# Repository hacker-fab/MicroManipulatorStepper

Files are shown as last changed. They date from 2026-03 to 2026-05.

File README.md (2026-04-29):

# HackerFab Nanopositioner

This repository contains **HackerFab’s extended version** of the open-source nanopositioner originally developed by Diffraction Limited.

We build directly on the original design and contribute additional capabilities, including:
- Rotational control
- Integrated heating
- Vacuum compatibility
- Ongoing improvements for lab use at HackerFab

## Credit

All core mechanical, electrical, and firmware design work is credited to the original project:

https://github.com/0x23/OpenMicroManipulator  

This repo is a derivative work that extends their platform for new use cases with additional custom made components. 

## Documentation

For build instructions, usage, and full system details, see the HackerFab documentation:

https://docs.hackerfab.org/home

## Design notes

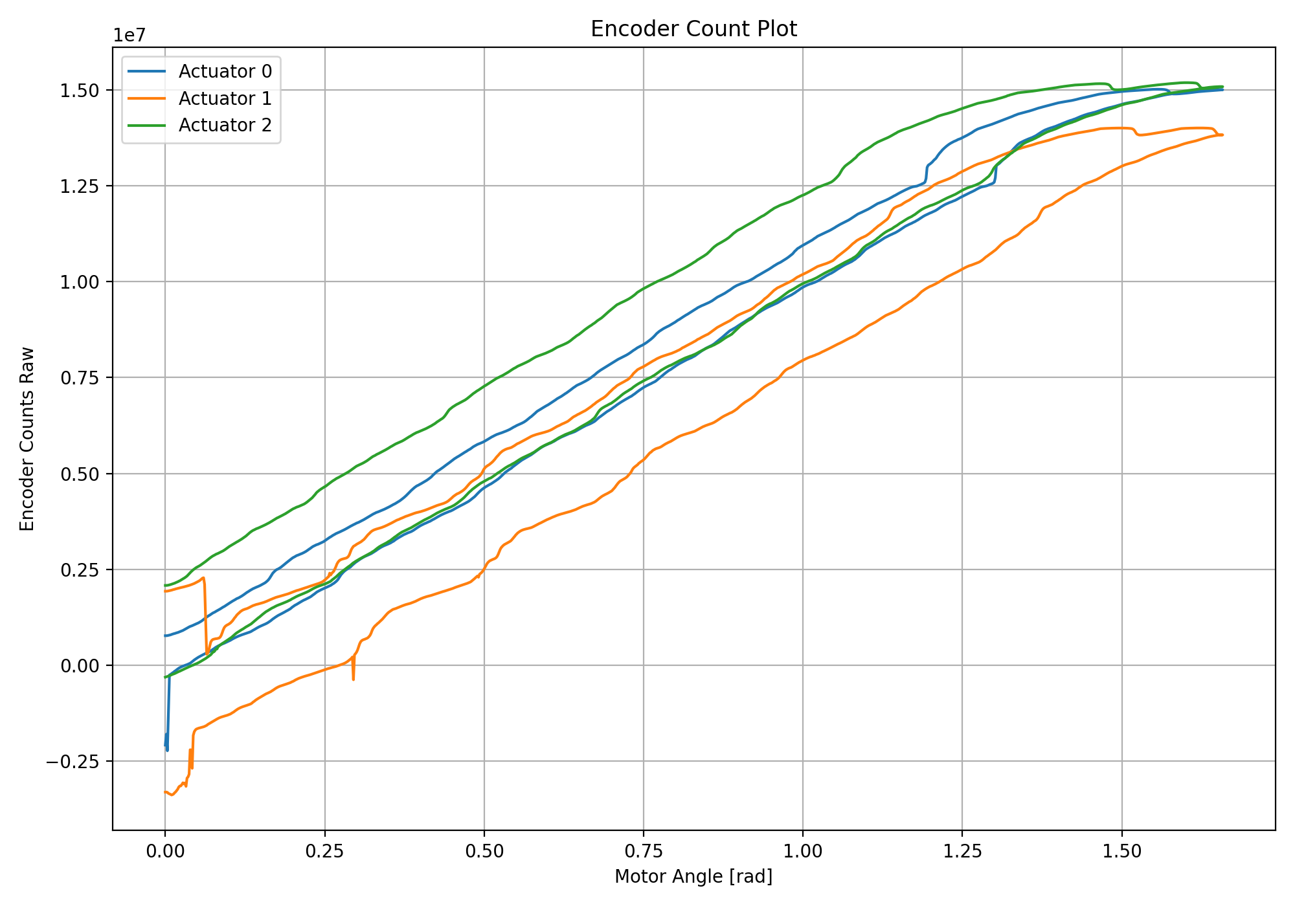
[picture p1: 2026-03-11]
software/PythonAPI/my_figure.png

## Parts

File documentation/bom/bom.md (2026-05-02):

# Bill of Materials (BOM)

## Mechanics

| Name | Qty | Description | Comments | Suggested link | Image |
|---|-----|---|---|---|---|
| Steel ball | 12 | Ø1 mm (0.04") | Precision G10 or better. Can be sourced from small ball bearings | |
| PU stretch cord | 1 m | Ø1mm | e.g. "Stretch Magic" or "Magic String" | [Aliexpress](https://www.aliexpress.us/item/3256805953910514.html)| Pu strech cord|
| Neodym Cylinder Magnet | 70 | Ø3mm h=5 mm | N52 Grade | [NeoMagnets](https://www.buyneomagnets.com/p/3mm-dia-x-5mm-thick-n52-neodymium-rare-earth-disc-magnets-100-pack/)|
| Brass Pipe | 1 m | OD=Ø2mm ID=Ø1 mm |  | [Amazon](https://a.co/d/1pRFmtf)| Brass Pipe|
| M2-8 dowel | 9 | | | | |
| SHCS M2-8 | 9 | | | | |
| Set Screw M3-6 | 3 | | | | |
| FHCS M3-6 | 3 | | | | |
| FHCS M3-10 | 9 | | | | |
| FHCS M3-20 | 12  | | | | |

## Electronics

| Name | Qty | Description | Comments | Suggested link | Image |
|---|-----|---|---|---|---|
| DC-DC Step Down Module | 1 | 4.75–23 V Step-Down Buck Converter |  | [Aliexpress](https://www.aliexpress.us/item/3256806752772875.html)| DC-DC Step Down|
| (1N5819) OR (PMEG4010) | 1 | Diode (through-hole or SMD) |  | |
| Raspberry Pi Pico 2 | 1 | Microcontroller board |  | | Raspberry Pi Pico 2|
| MT6835 Magnetic Encoder Module | 3 | Magnetic encoder |  | [Aliexpress](https://www.aliexpress.us/item/3256808005140674.html)| MT6835 Magnetic Encoder Module|
| TB6612FNG Driver | 3 | |  | [Aliexpress](https://www.aliexpress.us/item/3256806060073976.html)| TB6612FNG Driver|
| 470 µF Electrolytic Capacitor | 3 | > 100 µF | anything > 100µF will work well | |
| 10 µF Ceramic Capacitor 0603 | 3 | Optional |  | |
| 4.7 k Resistor 0603 | 2 | Optional |  | |
| 2 Pin Power Header | 1 | 7.5 mm pitch |  | |
| 4 Pin Header | 4 | 2.5 mm pitch |  | |
| 8 Pin Header | 1 | 2.0 mm pitch |  | |
| NEMA 17 Stepper Motor | 3 | Body ≤ 38 mm | Body length <= 38mm | |

## PCBs

| Name | Qty | Description | Comments | Image |
| --- | --- | --- | --- | ----- |
| Control Board | 1 | | | |
| balljoint_plate_pcb | 6 | | | |

## 3D Printing

| Name | Qty | Description | Comments | Image |
| --- | --- | --- | --- | --- |
| Motor Horn | 3 | | 0.4 mm+ nozzle may require post-processing | Motor Horn |
| RubberBandCollet | 12  | | 0.4 mm nozzle, 0.1mm Layer height + may require post-processing | Rubber Band Collet |
| Motor Mount | 3 | | | Motor Mount |
| End Effector | 1 | | | End Effector |
| Base Block | 1 | | | Base Block |

# Tool - Rod Sharpener

## 3D Printing

| Name | Qty | Description | Comments | Image |
| --- | --- | --- | --- | ----- |
| Rod Guide | 1 | | | |
| Blade Carrier | 1 | | | |

# Tool - Rod Length Setting Press

## PCBs

| Name | Qty | Description | Comments | Image |
| --- | --- | --- | --- | ----- |
| ball_alignment_disc_pcb | 1 | | | |

## 3D Printing 

| Name | Qty | Description | Comments | Image |
| --- | --- | --- | --- | ----- |
| RodGrindingJigA | 1 | | | |
| RodGrindingJigB | 1 | | | |
| RodGuide | 1 | | | |
| RodCollet | 2 | | | |
| CaliperClamp | 2 | | | |

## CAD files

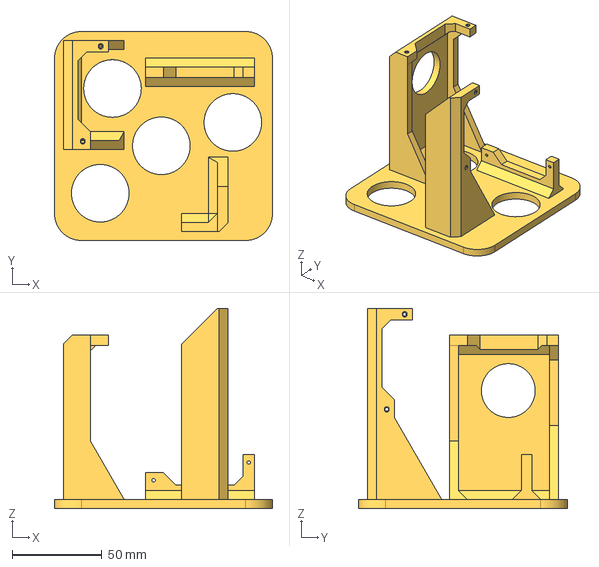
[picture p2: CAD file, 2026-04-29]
construction/Litho Base Mount.step
121.5 x 116.5 x 111.5 mm

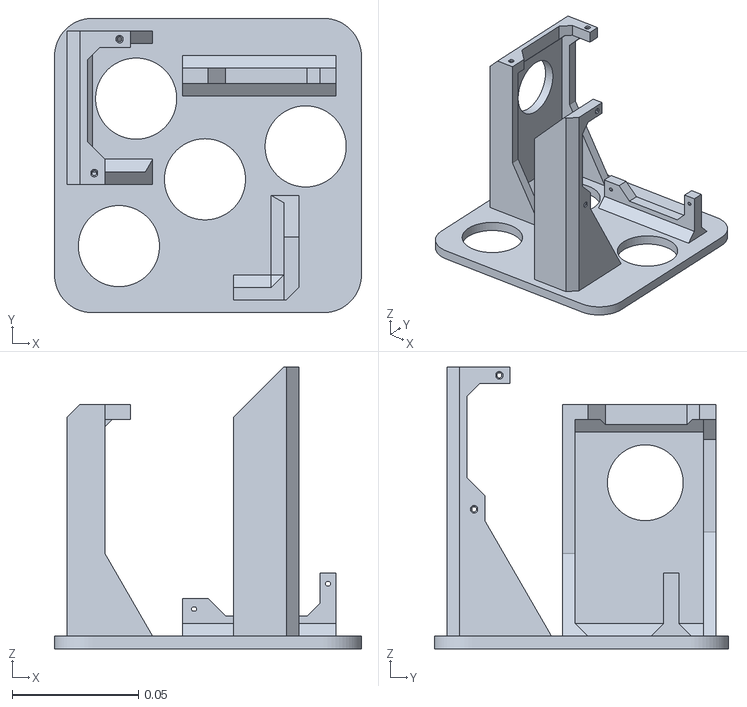
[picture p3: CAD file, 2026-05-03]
construction/v4_3dprinting_stl/machine/StandingBase.stl
0.122 x 0.116 x 0.112

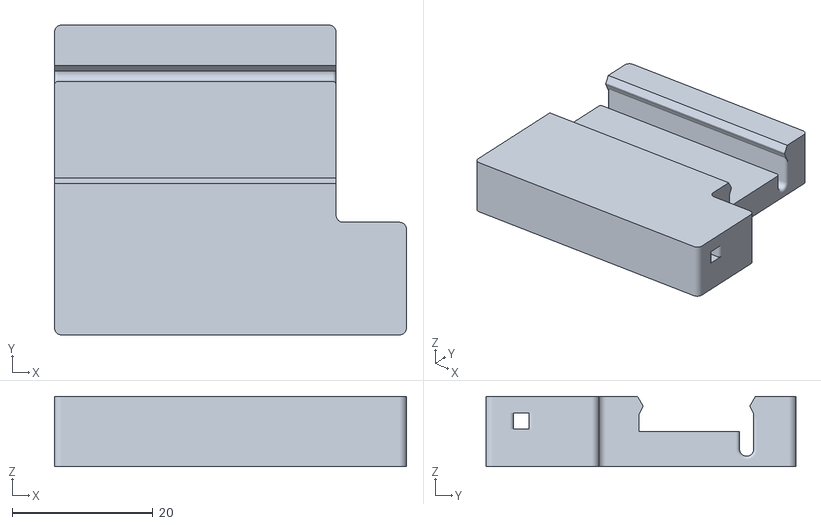
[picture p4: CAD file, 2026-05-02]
construction/v4_3dprinting_stl/tools/rod_length_setting_press/RodGuide.stl
50.0 x 44.0 x 10.0

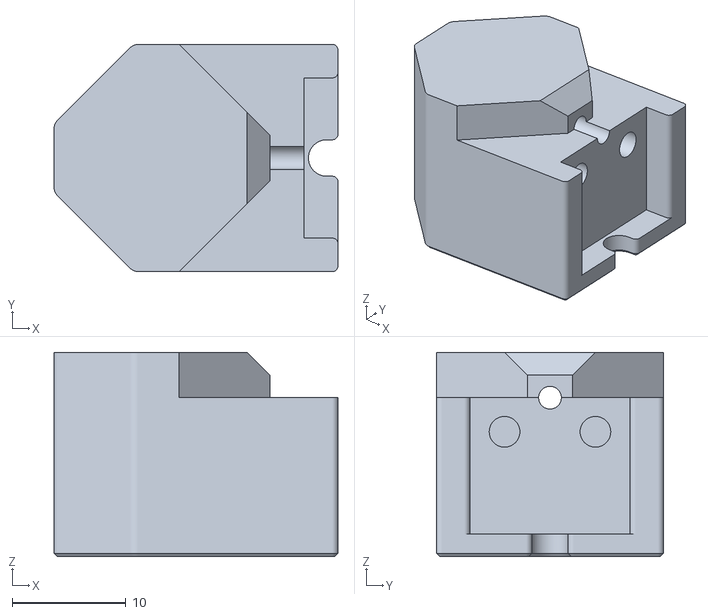
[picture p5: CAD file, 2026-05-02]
construction/v4_3dprinting_stl/tools/rod_sharpener/RodGuide.stl
25.0 x 20.0 x 18.0

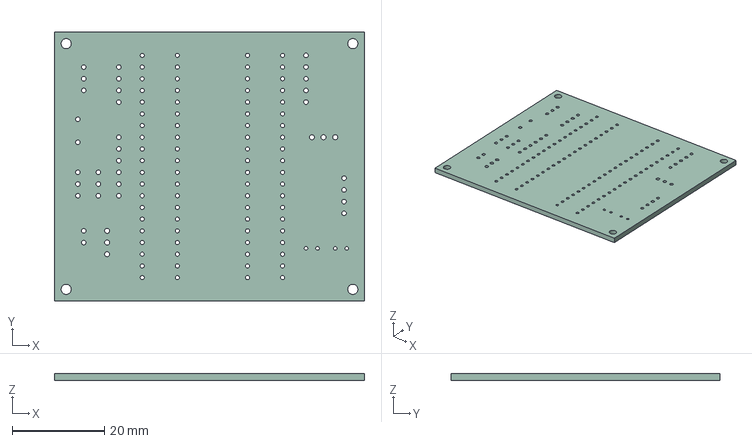
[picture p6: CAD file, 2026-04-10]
electronics/rot_platform_pcb/rot_platform_pcb.step
67.3 x 58.4 x 1.51 mm

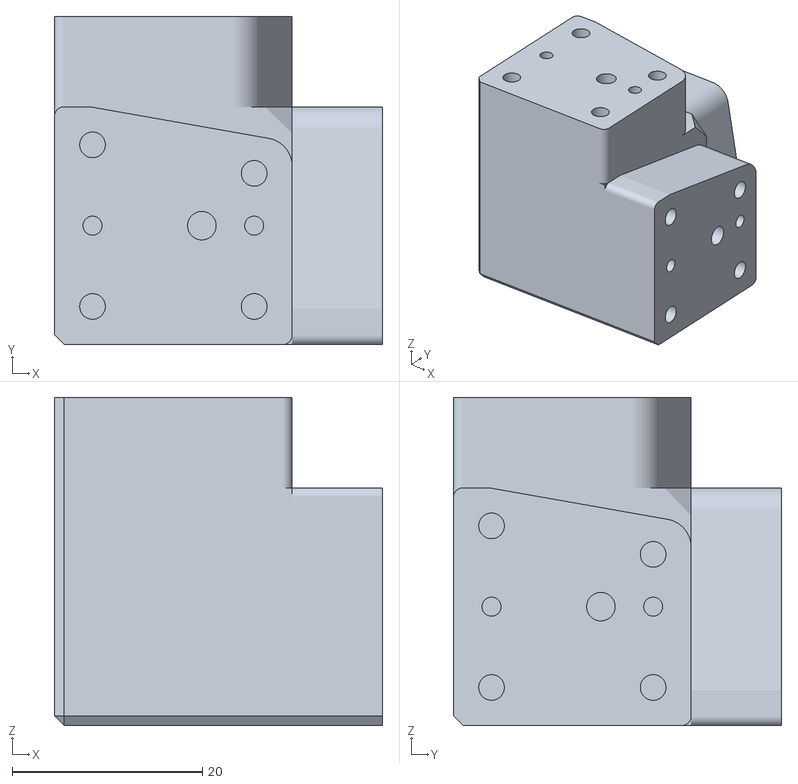
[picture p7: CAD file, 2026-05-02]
construction/v4_3dprinting_stl/machine/BaseBlock.stl
34.5 x 34.5 x 34.5

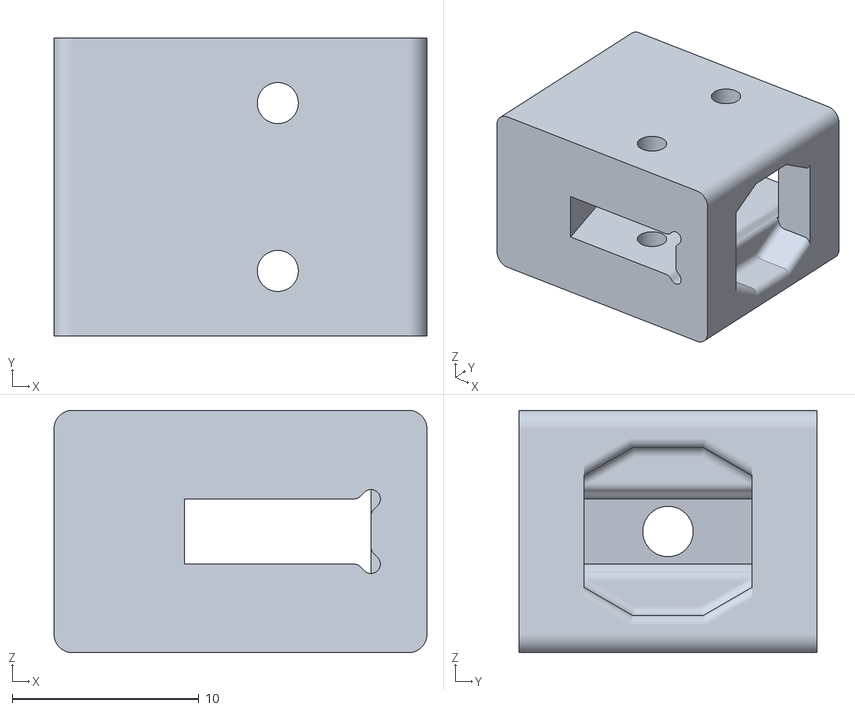
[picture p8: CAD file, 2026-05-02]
construction/v4_3dprinting_stl/tools/rod_length_setting_press/CaliperClamp.stl
20.0 x 16.0 x 13.0

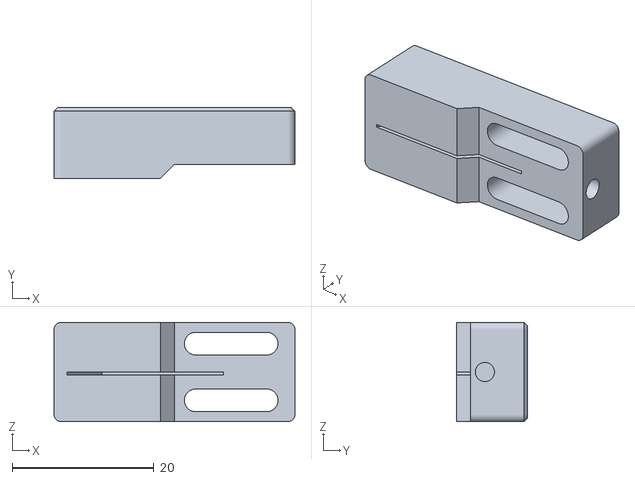
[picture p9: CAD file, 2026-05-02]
construction/v4_3dprinting_stl/tools/rod_sharpener/BladeCarrier.stl
34.0 x 10.0 x 14.0

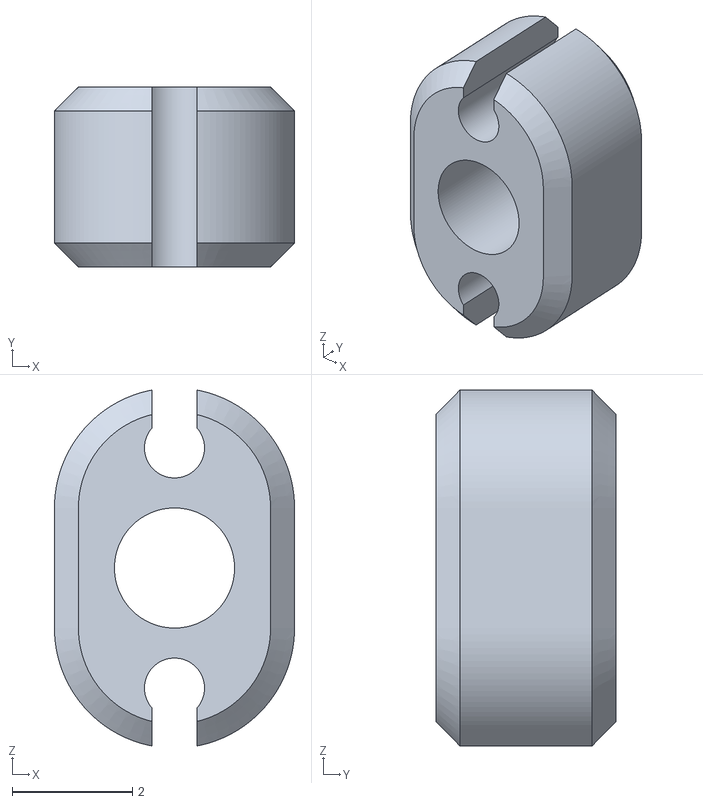
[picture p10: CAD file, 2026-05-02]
construction/v4_3dprinting_stl/machine/RubberBandCollet.stl
4.00 x 3.00 x 5.93

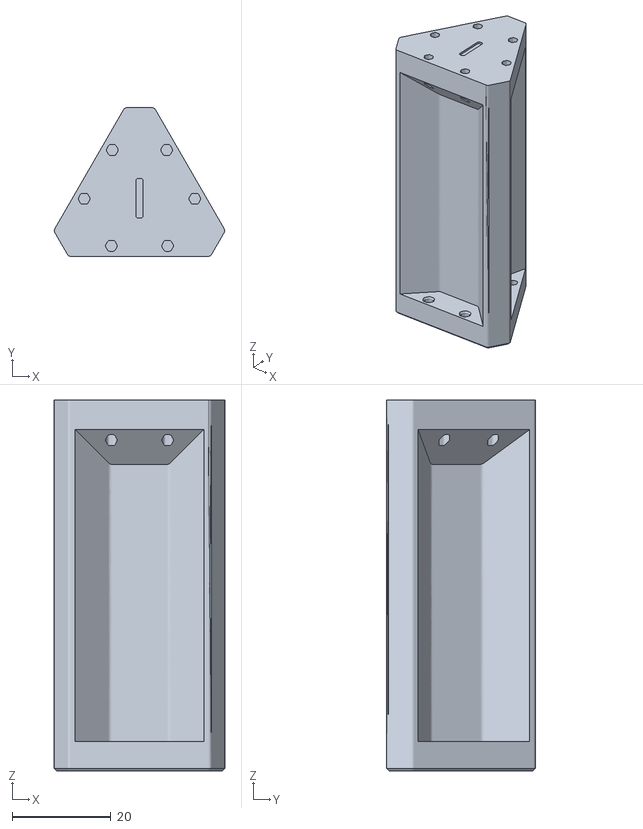
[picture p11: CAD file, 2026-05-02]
construction/v4_3dprinting_stl/tools/rod_length_setting_press/RodGrindingJigA.stl
34.5 x 30.1 x 75.0

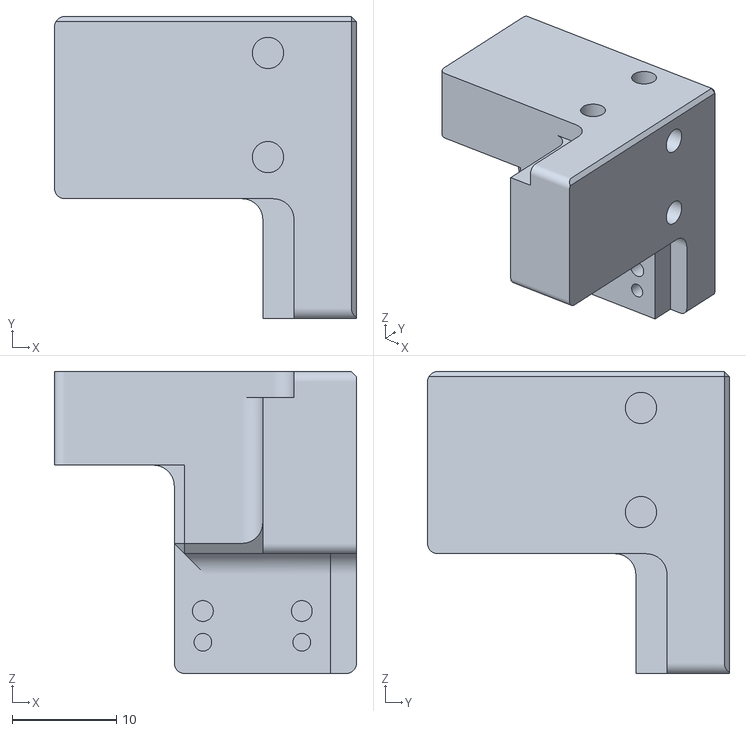
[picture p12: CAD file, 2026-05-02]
construction/v4_3dprinting_stl/machine/EndEffector.stl
29.0 x 29.0 x 29.0

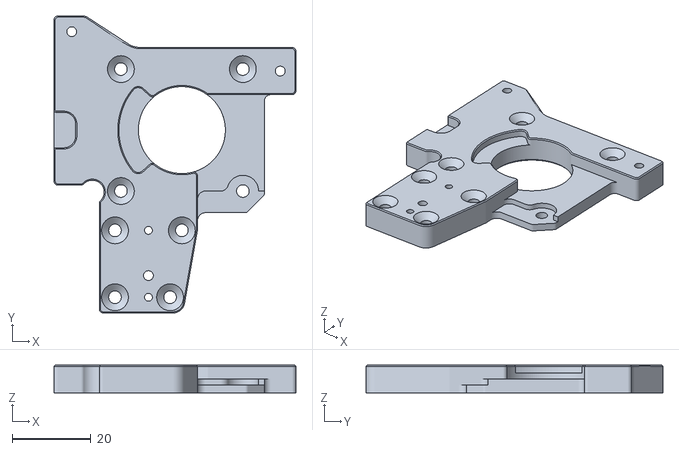
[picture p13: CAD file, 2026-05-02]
construction/v4_3dprinting_stl/machine/MotorMount.stl
61.5 x 75.5 x 7.00

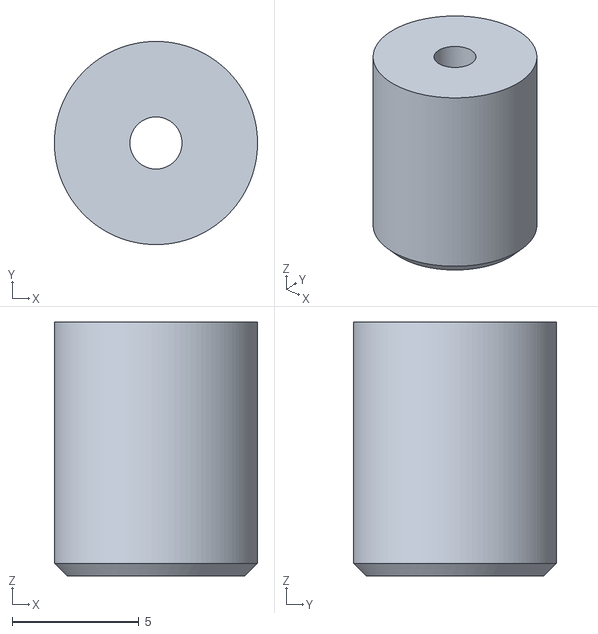
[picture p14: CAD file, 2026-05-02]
construction/v4_3dprinting_stl/tools/rod_length_setting_press/RodCollet.stl
8.00 x 8.00 x 10.0

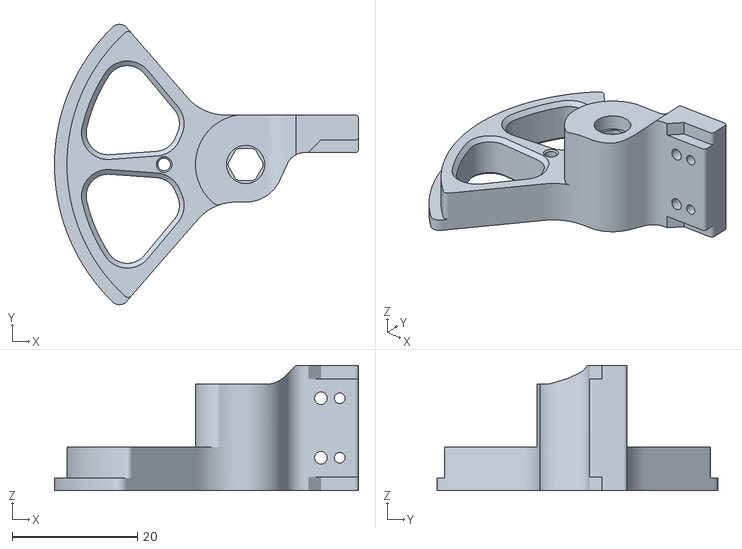
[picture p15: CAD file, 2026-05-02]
construction/v4_3dprinting_stl/machine/MotorHorn.stl
48.5 x 44.7 x 20.0

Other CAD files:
construction/v4_3dprinting_stl/tools/rod_length_setting_press/RodGrindingJigB.stl

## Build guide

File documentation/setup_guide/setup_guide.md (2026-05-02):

# Setup Guide

This guide walks you through the setup of your new **Open Micro-Manipulator** device.

## Checklist for New Devices

1. **Was the mechanical limit pin added to the rotor?**  
   This pin is required for proper homing of the device.

    <div style="display: flex;">
        Mechanical Limit Pin
    </div>

2. **Are the screws that secure the rotor to the motor shaft installed?**  
   If the rotor is not firmly attached, it may slip imperceptibly during homing or other movements, leading to problems during calibration and homing.

3. **Is the homing direction correct?**  
   During the homing command (`G28`), the end effector should move toward the base.  
   If it moves in the opposite direction, rewire the motor to reverse its direction.

   <div style="display: flex;">
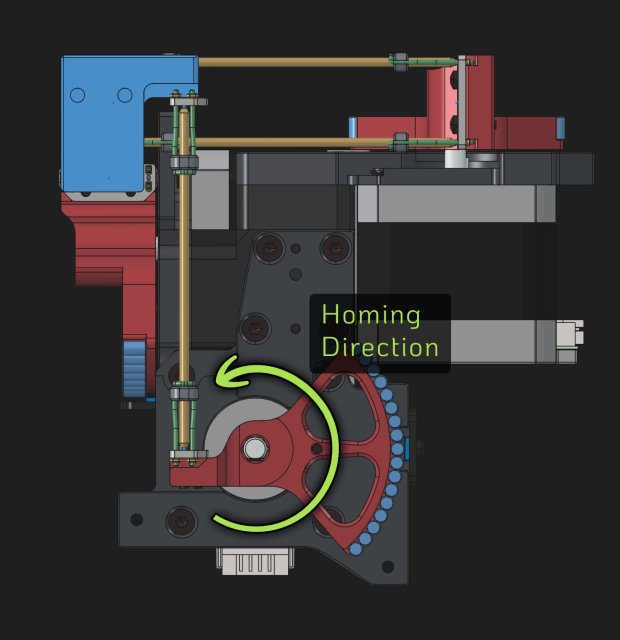
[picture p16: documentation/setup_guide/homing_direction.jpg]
Mechanical Limit Pin
       
   </div>

## Calibration and Checking the Encoders

You can use the calibration plotter to check if your encoders are working as expected.
On the left you see a good calibration on the right a bad calibration.

|  |  |
:--:|:--:
| **Good calibration** | **Bad calibration** |

THIS DOCUMENT IS UNFINISHED AND WORK IN PROGRESS...

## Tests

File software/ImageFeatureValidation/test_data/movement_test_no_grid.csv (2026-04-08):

x | y | feed | delay
0.000000 | 0.000000 | 10.0
0.001000 | 0.000000 | 50.0
0.002000 | 0.000000 | 50.0
0.001000 | 0.000000 | 50.0
0.000000 | 0.000000 | 50.0
0.000000 | 0.001000 | 50.0
0.000000 | 0.002000 | 50.0
0.000000 | 0.001000 | 50.0
0.000000 | 0.000000 | 50.0
0.000707 | 0.000707 | 50.0
0.001414 | 0.001414 | 50.0
0.000707 | 0.000707 | 50.0
0.000000 | 0.000000 | 50.0
-0.000707 | 0.000707 | 50.0
0.000000 | 0.001414 | 50.0
0.000707 | 0.000707 | 50.0
0.000000 | 0.000000 | 50.0
0.001000 | 0.000000 | 50.0
0.000293 | 0.000707 | 50.0
0.001000 | 0.001414 | 50.0
0.001707 | 0.000707 | 50.0
0.001000 | 0.000000 | 50.0
0.000000 | 0.000000 | 50.0
-0.000707 | -0.000707 | 50.0
0.000293 | -0.000707 | 50.0
0.001293 | -0.000707 | 50.0
0.000586 | 0.000000 | 50.0
0.000000 | 0.000000 | 50.0
0.001000 | 0.000000 | 50.0
0.002000 | 0.000000 | 50.0
0.001000 | 0.000000 | 50.0
0.000000 | 0.000000 | 50.0
0.000000 | 0.001000 | 50.0
0.000000 | 0.002000 | 50.0
0.000000 | 0.001000 | 50.0
0.000000 | 0.000000 | 50.0
0.000707 | 0.000707 | 50.0
0.001414 | 0.001414 | 50.0
0.000707 | 0.000707 | 50.0
0.000000 | 0.000000 | 50.0
-0.000707 | 0.000707 | 50.0
0.000000 | 0.001414 | 50.0
0.000707 | 0.000707 | 50.0
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

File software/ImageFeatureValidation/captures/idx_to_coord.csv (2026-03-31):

idx | x | y
0 | -7.0 | 0.0
1 | 0.001000000000000334 | 0.0
2 | 0.0019999999999997797 | 0.0
3 | 0.001000000000000334 | 0.0
4 | 0.0 | 0.0
5 | 0.0 | 0.001
6 | 0.0 | 0.002
7 | 0.0 | 0.001
8 | 0.0 | 0.0
9 | 0.0007070000000002352 | 0.000707
10 | 0.0014139999999995823 | 0.001414
11 | 0.0007070000000002352 | 0.000707
12 | 0.0 | 0.0
13 | -0.0007070000000002352 | 0.000707
14 | 0.0 | 0.001414
15 | 0.0007070000000002352 | 0.000707
16 | 0.0 | 0.0
17 | 0.001000000000000334 | 0.0
18 | 0.00029300000000009874 | 0.000707
19 | 0.001000000000000334 | 0.001414
20 | 0.001706999999999681 | 0.000707
21 | 0.001000000000000334 | 0.0
22 | 0.0 | 0.0
23 | -0.0007070000000002352 | -0.000707
24 | 0.00029300000000009874 | -0.000707
25 | 0.0012930000000004327 | -0.000707
26 | 0.0005860000000001975 | 0.0
27 | 0.0 | 0.0
28 | 0.001000000000000334 | 0.0
29 | 0.0019999999999997797 | 0.0
30 | 0.001000000000000334 | 0.0
31 | 0.0 | 0.0
32 | 0.0 | 0.001
33 | 0.0 | 0.002
34 | 0.0 | 0.001
35 | 0.0 | 0.0
36 | 0.0007070000000002352 | 0.000707
37 | 0.0014139999999995823 | 0.001414
38 | 0.0007070000000002352 | 0.000707
39 | 0.0 | 0.0
40 | -0.0007070000000002352 | 0.000707
41 | 0.0 | 0.001414
42 | 0.0007070000000002352 | 0.000707
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

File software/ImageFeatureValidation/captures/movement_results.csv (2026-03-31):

from_position | to_position | expected_distance_um | actual_distance_um | difference_um | feed
(-7.000000000,0.000000000) | (0.001000000,0.000000000) | 1.0 | 2.947063171070284 | 1.9470631710702841 | 50.0
(0.001000000,0.000000000) | (0.002000000,0.000000000) | 1.0 | 1.3242024965505383 | 0.32420249655053834 | 50.0
(0.002000000,0.000000000) | (0.001000000,0.000000000) | 1.0 | 0.9471770879675141 | -0.0528229120324859 | 50.0
(0.001000000,0.000000000) | (0.000000000,0.000000000) | 1.0 | 1.716676845021542 | 0.7166768450215419 | 50.0
(0.000000000,0.000000000) | (0.000000000,0.001000000) | 1.0 | 2.948005388172818 | 1.948005388172818 | 50.0
(0.000000000,0.001000000) | (0.000000000,0.002000000) | 1.0 | 2.1853585354504927 | 1.1853585354504927 | 50.0
(0.000000000,0.002000000) | (0.000000000,0.001000000) | 1.0 | 1.9705077073768327 | 0.9705077073768327 | 50.0
(0.000000000,0.001000000) | (0.000000000,0.000000000) | 1.0 | 2.121842257667226 | 1.1218422576672258 | 50.0
(0.000000000,0.000000000) | (0.000707000,0.000707000) | 0.999848988597778 | 2.44425217800624 | 1.4444031894084621 | 50.0
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

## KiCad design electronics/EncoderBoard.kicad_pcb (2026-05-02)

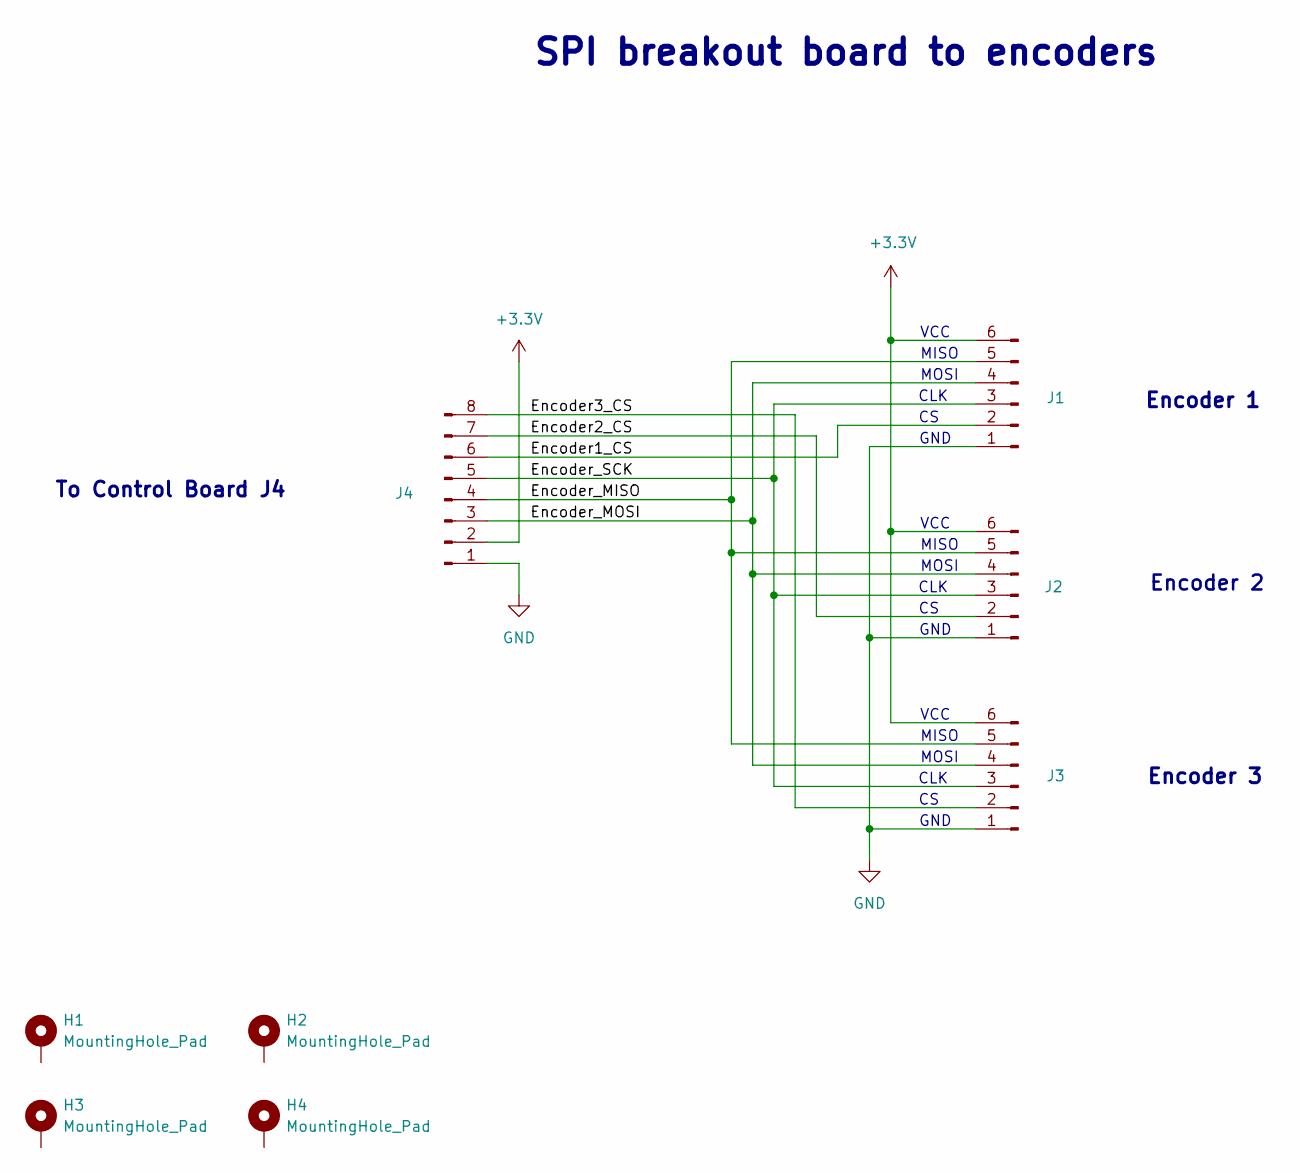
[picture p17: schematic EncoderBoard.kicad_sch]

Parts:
H1, H2, H3, H4: MountingHole_Pad; MountingHole_2.7mm_M2.5_Pad_Via
J1, J2, J3: Conn_01x06_Pin; JST_PH_B6B-PH-K_1x06_P2.00mm_Vertical
J4: Conn_01x08_Pin; JST_PH_B8B-PH-K_1x08_P2.00mm_Vertical

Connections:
+3.3V: J1.6, J2.6, J3.6, J4.2
/Encoder1_CS: J1.2, J4.6
/Encoder2_CS: J2.2, J4.7
/Encoder3_CS: J3.2, J4.8
/Encoder_MISO: J1.5, J2.5, J3.5, J4.4
/Encoder_MOSI: J1.4, J2.4, J3.4, J4.3
/Encoder_SCK: J1.3, J2.3, J3.3, J4.5
GND: J1.1, J2.1, J3.1, J4.1

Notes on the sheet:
VCC
Encoder 2
CLK
MISO
To Control Board J4
MOSI
Encoder 3
SPI breakout board to encoders
GND
Encoder 1

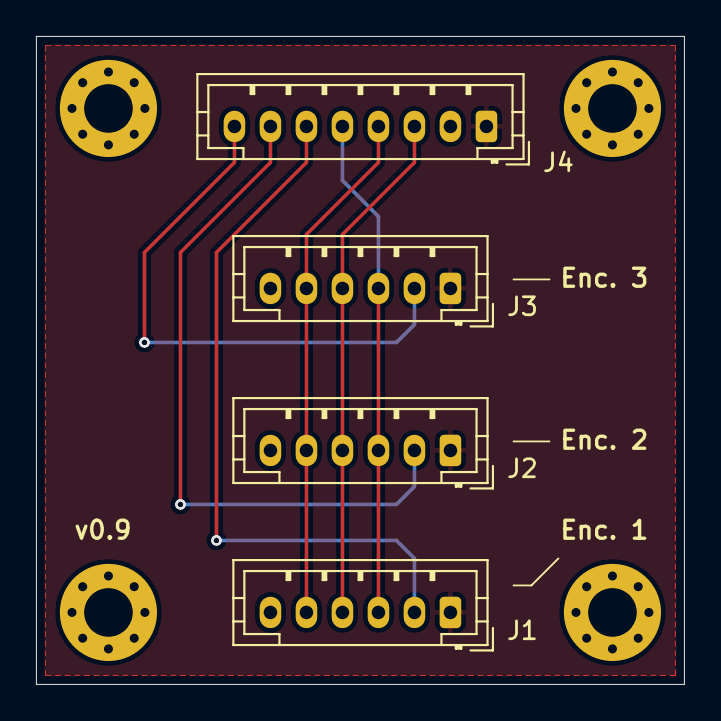
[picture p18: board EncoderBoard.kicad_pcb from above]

Board: 2 copper layers, 36.0 x 36.0 mm, 8 parts (0 on the bottom side), 8 nets.

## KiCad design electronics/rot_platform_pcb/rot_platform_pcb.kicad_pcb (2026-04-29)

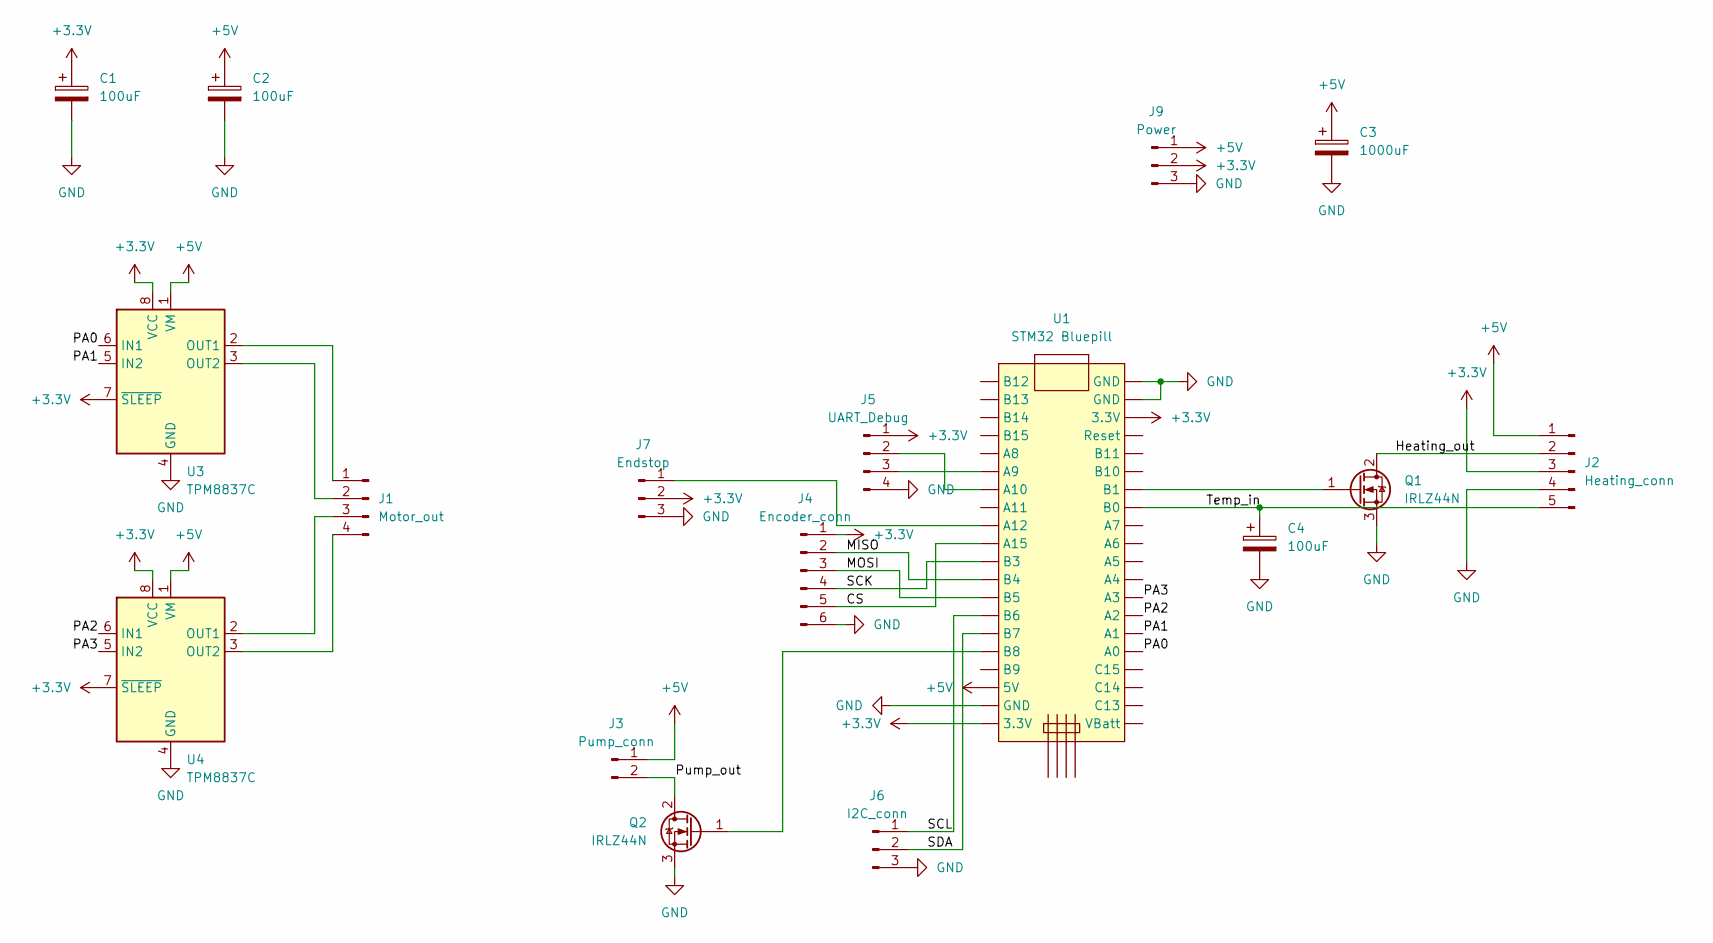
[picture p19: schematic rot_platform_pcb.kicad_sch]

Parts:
C1, C2, C4: 100uF; CP_Radial_D5.0mm_P2.50mm
C3: 1000uF; CP_Radial_D10.0mm_P5.00mm
J1: Motor_out; PinHeader_1x04_P2.54mm_Vertical
J2: Heating_conn; PinHeader_1x05_P2.54mm_Vertical
J3: Pump_conn; PinHeader_1x02_P2.54mm_Vertical
J4: Encoder_conn; PinHeader_1x06_P2.54mm_Vertical
J5: UART_Debug; PinHeader_1x04_P2.54mm_Vertical
J6: I2C_conn; PinHeader_1x03_P2.54mm_Vertical
J7: Endstop; PinHeader_1x03_P2.54mm_Vertical
J9: Power; PinHeader_1x03_P2.54mm_Vertical
Q1, Q2: IRLZ44N; TO-220-3_Vertical
U1: STM32 Bluepill; stm32_bluepill
U3, U4: TPM8837C; SOIC-8-1EP_3.9x4.9mm_P1.27mm_EP2.29x3mm

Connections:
+3.3V: C1.1, J2.3, J4.1, J5.1, J7.2, J9.2, U1.20 (3.3V), U1.38 (3.3V), U3.7 (~SLEEP), U3.8 (VCC), U4.7 (~SLEEP), U4.8 (VCC)
+5V: C2.1, C3.1, J2.1, J3.1, J9.1, U1.18 (5V), U3.1 (VM), U4.1 (VM)
/CS: J4.5, U1.10 (A15)
/Heating_out: J2.2, Q1.2 (D)
/MISO: J4.2, U1.12 (B4)
/MOSI: J4.3, U1.13 (B5)
/PA0: U1.25 (A0), U3.6 (IN1)
/PA1: U1.26 (A1), U3.5 (IN2)
/PA2: U1.27 (A2), U4.6 (IN1)
/PA3: U1.28 (A3), U4.5 (IN2)
/Pump_out: J3.2, Q2.2 (D)
/SCK: J4.4, U1.11 (B3)
/SCL: J6.1, U1.14 (B6)
/SDA: J6.2, U1.15 (B7)
/Temp_in: C4.1, J2.5, U1.33 (B0)
GND: C1.2, C2.2, C3.2, C4.2, J2.4, J4.6, J5.4, J6.3, J7.3, J9.3, Q1.3 (S), Q2.3 (S), U1.19 (GND), U1.39 (GND), U1.40 (GND), U3.4 (GND), U3.9 (GND), U4.4 (GND), U4.9 (GND)
unnamed: J1.1, U3.2 (OUT1)
unnamed: J1.2, U3.3 (OUT2)
unnamed: J1.3, U4.2 (OUT1)
unnamed: J1.4, U4.3 (OUT2)
unnamed: J5.2, U1.7 (A10)
unnamed: J5.3, U1.6 (A9)
unnamed: J7.1, U1.9 (A12)
unnamed: Q1.1 (G), U1.34 (B1)
unnamed: Q2.1 (G), U1.16 (B8)

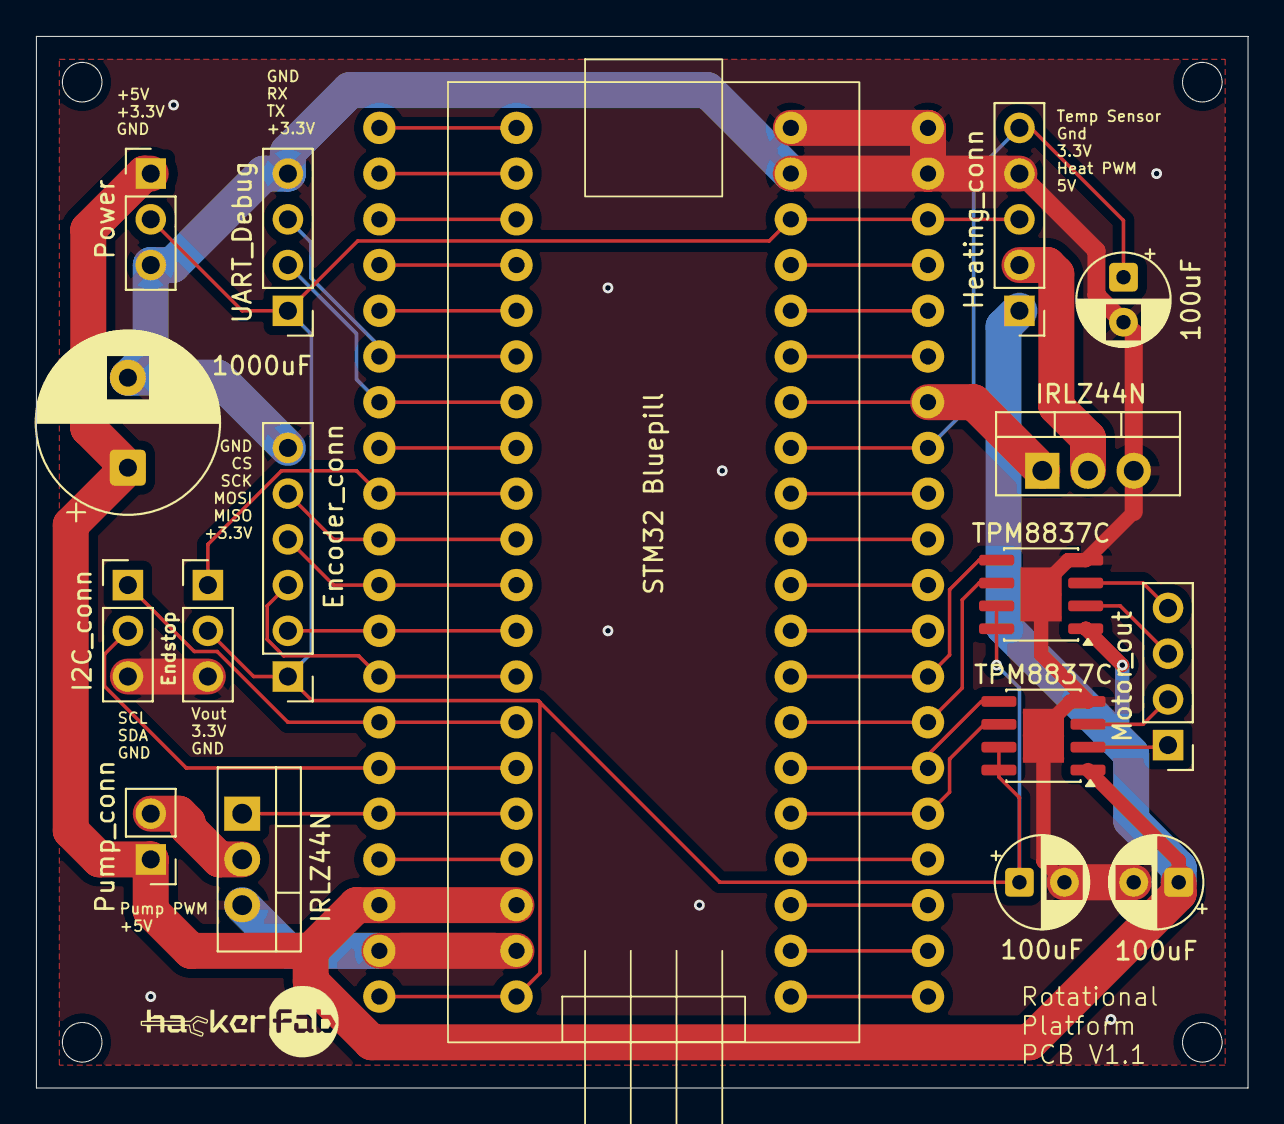
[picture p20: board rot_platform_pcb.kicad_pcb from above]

Board: 2 copper layers, 67.3 x 58.4 mm, 17 parts (0 on the bottom side), 25 nets.

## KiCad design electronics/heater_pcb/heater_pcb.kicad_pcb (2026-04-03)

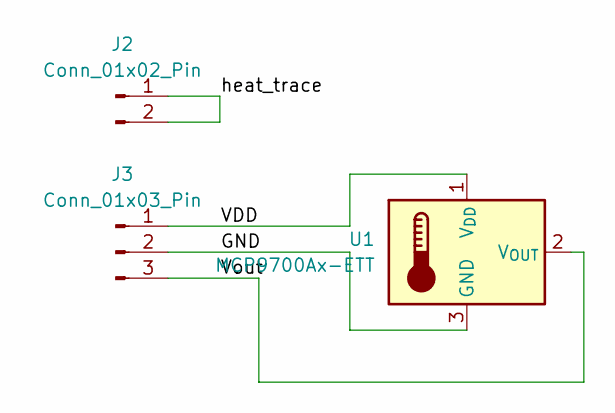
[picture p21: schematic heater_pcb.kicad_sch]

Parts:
J2: Conn_01x02_Pin; PinHeader_1x02_P2.54mm_Vertical
J3: Conn_01x03_Pin; PinHeader_1x03_P2.54mm_Vertical
U1: MCP9700Ax-ETT; SOT-23

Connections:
/GND: J3.2, U1.3 (GND)
/VDD: J3.1, U1.1 (V_{DD})
/Vout: J3.3, U1.2 (V_{OUT})
/heat_trace: J2.1, J2.2

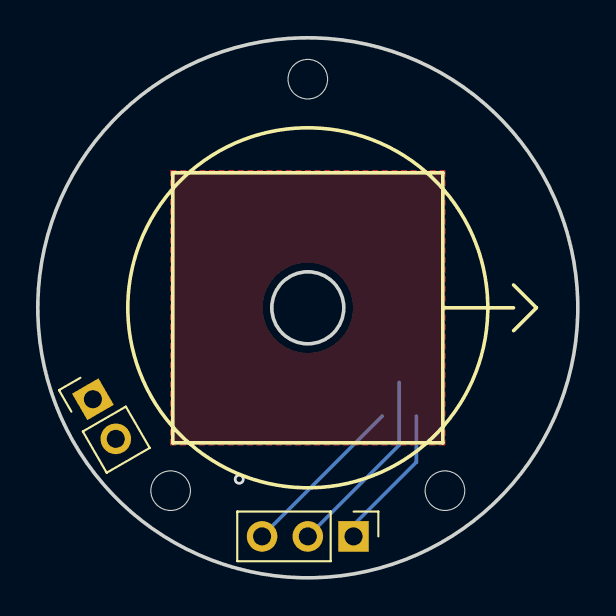
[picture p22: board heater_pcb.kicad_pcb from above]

Board: 4 copper layers, 30.0 x 30.0 mm, 3 parts (1 on the bottom side), 4 nets.

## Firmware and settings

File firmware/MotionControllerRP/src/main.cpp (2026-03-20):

// --------------------------------------------------------------------------------------
// Project: MicroManipulatorStepper
// License: MIT (see LICENSE file for full description)
//          All text in here must be included in any redistribution.
// Author:  M. S. (diffraction limited)
// --------------------------------------------------------------------------------------

#include "main.h"

#include "hardware/clocks.h"
#include "hardware/pll.h"
#include "hardware/vreg.h"

#include <Wire.h>
#include <algorithm>

#include "robot.h"
#include "utilities/logging.h"
#include "utilities/frequency_counter.h"
#include "kinematic_models/kinematic_model_delta3d.h"
#include "version.h"
#include "hw_config.h"
#include "LittleFS.h"

#include "demo_gcode_generator.h"

//*** GLOBALS ***************************************************************************

// NeoPixelConnect strip(PIN_BUILTIN_LED, 1);
Robot robot(0.01f);

/*
MT6835Encoder encoder1(spi0, PIN_ENCODER1_CS);
MT6835Encoder encoder2(spi0, PIN_ENCODER2_CS);
MT6835Encoder encoder3(spi0, PIN_ENCODER3_CS);

TB6612MotorDriver motor_driver1(
  PIN_MOTOR_EN, PIN_M1_PWM_A_POS, PIN_M1_PWM_A_NEG, PIN_MOTOR_PWMAB,
  PIN_MOTOR_EN, PIN_M1_PWM_B_POS, PIN_M1_PWM_B_NEG, PIN_MOTOR_PWMAB
);
TB6612MotorDriver motor_driver2(
  PIN_MOTOR_EN, PIN_M2_PWM_A_POS, PIN_M2_PWM_A_NEG, PIN_MOTOR_PWMAB,
  PIN_MOTOR_EN, PIN_M2_PWM_B_POS, PIN_M2_PWM_B_NEG, PIN_MOTOR_PWMAB
);
TB6612MotorDriver motor_driver3(
  PIN_MOTOR_EN, PIN_M3_PWM_A_POS, PIN_M3_PWM_A_NEG, PIN_MOTOR_PWMAB,
  PIN_MOTOR_EN, PIN_M3_PWM_B_POS, PIN_M3_PWM_B_NEG, PIN_MOTOR_PWMAB
);

ServoController servo_controller1(motor_driver1, encoder1, 400/4);
ServoController servo_controller2(motor_driver2, encoder2, 400/4);
ServoController servo_controller3(motor_driver3, encoder3, 400/4);
FrequencyCounter loop_freq_counter(1000);

PathPlanner planner(0.01f);
MotionController motion_controller(&planner);
Pose6DF current_pose;

CommandParser command_parser; */

//*** FUNCTIONS *************************************************************************

// Run before setup()
//__attribute__((constructor))
void overclock() {
  vreg_set_voltage(VREG_VOLTAGE_1_20);         // For >133 MHz
  busy_wait_us(10 * 1000);  // 10 ms delay
  set_sys_clock_khz(250000, true);             // Set to 250 MHz
}

void set_led_color(uint8_t r, uint8_t g, uint8_t b) {
 /* strip.neoPixelSetValue(0, r, g, b, false);
  delayMicroseconds(2000);
  strip.neoPixelShow(); */
}

void led_blink(uint8_t r, uint8_t g, uint8_t b, int count, int period_time_ms) {
  for(int i=0; i<count; i++) {
    gpio_put(PIN_BUILTIN_LED, 1);
    // set_led_color(r, g, b);
    sleep_ms(period_time_ms/2);
    // set_led_color(0, 0, 0);
    gpio_put(PIN_BUILTIN_LED, 0);
    sleep_ms(period_time_ms/2);
  }
}

void main_core0() {
  uint64_t last_time = time_us_64();

  #ifdef DEMO_MODE
    auto* demo_gcode_generator = new DemoGcodeGenerator(&robot);
    demo_gcode_generator->run();  // blocks forever
  #endif

  while(true) {
    // update motion controller
    robot.update_command_parser();
    robot.update_path_planner();
  }
}

void main_core1() {
  LOG_INFO("Starting servo controll loops on core 1...");

  uint64_t last_time = time_us_64();
  while(true) {
    // get time and detla time
    uint64_t time_us = time_us_64();
    float dt = float(time_us - last_time)*1e-6f;
    last_time = time_us;

    // limit time delta
    dt = std::min(dt, 0.0001f);

    // update servo loops
    robot.update_servo_controllers(dt);
  }
}

void setup() {
  gpio_init(PIN_BUILTIN_LED);
  gpio_set_dir(PIN_BUILTIN_LED, GPIO_OUT);
  
  led_blink(0, 0, 30, 3, 100);
  // stdio_init_all();  // Initializes USB or UART stdio
  overclock();
  // Serial.begin(921600);
  Logger::instance().begin(921600, false);
  #ifndef DEMO_MODE
  while(!Serial);
  #endif

  set_led_color(50, 10, 0);
  // auto* test = new KinematicModel_Delta3D(); test->test(); delete test;

  delay(100);  // Allow time for serial monitor to connect
  
  LOG_INFO("Open Micro Stage Firmware: %s", FIRMWARE_VERSION);
  LOG_INFO("System clock: %i Mhz", int32_t(clock_get_hz(clk_sys))/1000/1000);

  // LittleFS.format();
  if (!LittleFS.begin()) {
    LOG_ERROR("Mounting filesystem failed");
  } else {
    FSInfo fs_info;
    LittleFS.info(fs_info);
    LOG_INFO("Mounting filesystem successfully [%i/%i bytes used]", 
             (int)fs_info.usedBytes, (int)fs_info.totalBytes);
  } 

  /*
  LookupTable enc_to_pos_lut;
  bool res = true; 
  res &= load_lut_from_file(enc_to_pos_lut, "joint_0_pos_to_field_lut.dat");
  for(uint32_t i=0; i<enc_to_pos_lut.size(); i++) {
    float v = enc_to_pos_lut.get_entry(i);
    Serial.printf("%i, %d\n", i, int(v*1000));
  }

    // Close files
  Serial.println("File print complete");*/
  LOG_INFO("Initializing device...");
  robot.init();

  multicore_launch_core1(&main_core1);
  sleep_ms(100);
  
  set_led_color(0, 20, 0);
  LOG_INFO("Initialization finished");
  LOG_INFO(" ");

  gpio_put(PIN_BUILTIN_LED, 1);

  return;

  /*
  rotencoder_wire.setSDA(PIN_ENCODER_SDA);
  rotencoder_wire.setSCL(PIN_ENCODER_SCL);
  rotencoder_wire.begin();
  rotencoder_wire.setClock(1000000);
  encoder.init();
  encoder.set_hysteresis(0x4); //0x6);
  */
}

void loop() {
  main_core0();
}

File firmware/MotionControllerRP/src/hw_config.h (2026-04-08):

#pragma once
#include "utilities/math_constants.h"

// #define DEMO_MODE

//--- MOTORS ------------------------------------------------------------------

// motor pole pair count
//  * 100 for 0.9deg stepper motors
//  * 50  for 1.8deg stepper motors
constexpr float MOTOR1_POLE_PAIRS = 50;
constexpr float MOTOR2_POLE_PAIRS = 50;
constexpr float MOTOR3_POLE_PAIRS = 50;

// max current factor in range [0..1]. Lower values reduce pwm resolution so a
// value above 0.4 is recommended.
constexpr float MOTOR_MAX_CURRENT_FACTOR = 0.6f;

//--- ENCODERS ----------------------------------------------------------------

// Conversion factor from encoder angle (one 2pi period every two magnets) to rotor angle.
// Used when the system can not rely on calibration data being present (e.g. during homing)
constexpr float ENCODER_MAGNET_PITCH = 3.0f;    // [mm]
constexpr float ENCODER_MAGNET_RADIUS = 30.0f;  // [mm]
constexpr float ENCODER_ANGLE_TO_ROTOR_ANGLE = (ENCODER_MAGNET_PITCH*2.0f) / 
                                               (ENCODER_MAGNET_RADIUS * Constants::TWO_PI_F);
											   
// enables error checking for encoders (slow) - useful for debugging
// Note: some chips seem to return always a crc of 0 producing massiv false errors       
constexpr bool ENABLE_ENCODER_CRC = false;

//--- HOMING ------------------------------------------------------------------

constexpr float HOMING_VELOCITY   = 1.0f;        // rad per s
constexpr float HOMING_CURRENT    = 0.5f;       // range 0..1
// NOT IMPLEMENTED YET: constexpr float HOMING_FINISH_POS = 0.5f;        // in rad
constexpr float HOMING_RETRACTION_FIELD_ANGLE = 8.0f;
constexpr float HOMING_RETRACTION_Z_FIELD_ANGLE = 4.0f;
constexpr float CALIBRATION_RETRACTION_FIELD_ANGLE = 0.25f;

//--- CALIBRATION -------------------------------------------------------------

// degrees from home position
constexpr float CALIBRATION_RANGE = 75; 

// velocity of the magnetic field during calibration (lower is more accurate)
constexpr float CALIBRATION_FIELD_VELOCITY = 20.0f; 

// size of the calibration lookup table
constexpr int ENCODER_LUT_SIZE = 256;

//--- CLOSED LOOP CONTROL -----------------------------------------------------

// position controller 
constexpr float POS_KP = 60.0f;
constexpr float POS_KI = 30000.0f;

// velocity controller
constexpr float VEL_LOWPASS_TC = 0.004f;
constexpr float VEL_KP = 0.2f;
constexpr float VEL_KI = 90.0f;

//--- KINEMATIC ---------------------------------------------------------------

// Kinematic Parameters are defined kinematic_modes/kinematic_model_delta3d.cpp

// NUM_JOINTS and NUM_TOOLS are defined in 'path_segment.h'. Note that changing
// the number of joints requires changing the kinematic model accordingly and
// also requires the initialization of the correct number of 'RobotJoint' objects
// in the Robtos init method.

//--- PINS --------------------------------------------------------------------

#define JOINT_READY_OVERRIDE

// #define SINGLE_AXIS_BOARD
#ifndef SINGLE_AXIS_BOARD
  // Pins for 3Axis Board
  // #define PIN_BUILTIN_LED 23 // RP2040 pico clone
  // #define PIN_USER_BUTTON 24 // RP2040 pico clone
  #define PIN_BUILTIN_LED 25

  #define PIN_M1_PWM_A_POS  13
  #define PIN_M1_PWM_A_NEG  12
  #define PIN_M1_PWM_B_POS  14
  #define PIN_M1_PWM_B_NEG  15

  #define PIN_M2_PWM_A_POS  9
  #define PIN_M2_PWM_A_NEG  8
  #define PIN_M2_PWM_B_POS  10
  #define PIN_M2_PWM_B_NEG  11

  #define PIN_M3_PWM_A_POS  5
  #define PIN_M3_PWM_A_NEG  4
  #define PIN_M3_PWM_B_POS  6
  #define PIN_M3_PWM_B_NEG  7


  #define PIN_MOTOR_EN      18
  #define PIN_MOTOR_PWMAB   19

  #define PIN_ENCODER1_CS 20
  #define PIN_ENCODER2_CS 21
  #define PIN_ENCODER3_CS 22
  #define PIN_ENCODER_SCK 2
  #define PIN_ENCODER_MISO 0
  #define PIN_ENCODER_MOSI 3

  #define PIN_TOOL1 16
  #define PIN_TOOL2 17

#else
  // Single Axis Board
  #define PIN_BUILTIN_LED 16
  #define PIN_USER_BUTTON 24

  #define PIN_M1_PWM_A_POS  13
  #define PIN_M1_PWM_A_NEG  12
  #define PIN_M1_PWM_B_POS  14
  #define PIN_M1_PWM_B_NEG  15

  #define PIN_M2_PWM_A_POS  9
  #define PIN_M2_PWM_A_NEG  8
  #define PIN_M2_PWM_B_POS  10
  #define PIN_M2_PWM_B_NEG  11

  #define PIN_M3_PWM_A_POS  5
  #define PIN_M3_PWM_A_NEG  4
  #define PIN_M3_PWM_B_POS  6
  #define PIN_M3_PWM_B_NEG  7


  #define PIN_MOTOR_EN      18
  #define PIN_MOTOR_PWMAB   19

  #define PIN_ENCODER1_CS 20
  #define PIN_ENCODER2_CS 21
  #define PIN_ENCODER3_CS 22
  #define PIN_ENCODER_SCK 2
  #define PIN_ENCODER_MISO 0
  #define PIN_ENCODER_MOSI 3
#endif

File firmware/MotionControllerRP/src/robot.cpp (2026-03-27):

// --------------------------------------------------------------------------------------
// Project: MicroManipulatorStepper
// License: MIT (see LICENSE file for full description)
//          All text in here must be included in any redistribution.
// Author:  M. S. (diffraction limited)
// --------------------------------------------------------------------------------------

#include <LittleFS.h> 
#include "robot.h"
#include "hw_config.h"
#include "utilities/logging.h"
#include "utilities/utilities.h"
#include "kinematic_models/kinematic_model_delta3d.h"
#include "servo_control/homing_controller.h"
#include "servo_control/actuator_calibration.h"
#include "robot_joint/robot_joint.h"
#include "pico/multicore.h"
#include "version.h"
#include "robot_tool/pwm_tool.h"

constexpr int SPINLOCK_ID_SHARED_DATA = 0;
constexpr int SPINLOCK_ID_JOINTS = 1;

#include <NeoPixelConnect.h>
NeoPixelConnect led(PIN_BUILTIN_LED, 1);

//*** FUNCTION **************************************************************************

bool startswith(const std::string& str, const std::string& prefix) {
    return str.size() >= prefix.size() &&
           std::equal(prefix.begin(), prefix.end(), str.begin());
}

//*** CLASS *****************************************************************************

//--- Robot -----------------------------------------------------------------------------

Robot::Robot(float path_segment_time_step) : 
  path_planner(nullptr, path_segment_time_step), 
  motion_controller(&path_planner),
  servo_loop_frequency_counter(10000),
  motion_controller_frequency_counter(1000),
  shared_data(SPINLOCK_ID_SHARED_DATA),
  joints_spin_lock(spin_lock_instance(SPINLOCK_ID_JOINTS))
{
  kinematic_model = new KinematicModel_Delta3D();
  path_planner.set_kinematic_model(kinematic_model);  

  for(int i=0; i<NUM_JOINTS; i++)
    joints[i] = nullptr;

  command_parser.set_command_processor(this);

  current_feedrate = LinearAngular(10.0f, 1.0f);
  max_acceleration = LinearAngular(500.0f, 50.0f);
  path_buffering_time_us = 50*1e3;

  for(int i=0; i<NUM_TOOLS; i++)
    robot_tools[i] = nullptr;

  state = ERobotState::IDLE;
}

Robot::~Robot() {
  if(kinematic_model != nullptr)
    delete kinematic_model;

  for(int i=0; i<NUM_JOINTS; i++) {
    if(joints[i] != nullptr)
      delete joints[i];
    joints[i] = nullptr;
  }
}

void Robot::init() {
  MT6835Encoder::setup_spi(spi0, PIN_ENCODER_SCK, PIN_ENCODER_MOSI, PIN_ENCODER_MISO, 1000000);

  // axis 1
  {
    auto* encoder = new MT6835Encoder(spi0, PIN_ENCODER1_CS);
    auto* motor_driver = new TB6612MotorDriver(
      PIN_MOTOR_EN, PIN_M1_PWM_A_POS, PIN_M1_PWM_A_NEG, PIN_MOTOR_PWMAB,
      PIN_MOTOR_EN, PIN_M1_PWM_B_POS, PIN_M1_PWM_B_NEG, PIN_MOTOR_PWMAB
    );
	encoder->set_crc_enabled(ENABLE_ENCODER_CRC);
    joints[0] = new RobotJoint(encoder, motor_driver, MOTOR1_POLE_PAIRS);
  }

  // axis 2
  {
    auto* encoder = new MT6835Encoder(spi0, PIN_ENCODER2_CS);
    auto* motor_driver = new TB6612MotorDriver(
      PIN_MOTOR_EN, PIN_M2_PWM_A_POS, PIN_M2_PWM_A_NEG, PIN_MOTOR_PWMAB,
      PIN_MOTOR_EN, PIN_M2_PWM_B_POS, PIN_M2_PWM_B_NEG, PIN_MOTOR_PWMAB
    );
	encoder->set_crc_enabled(ENABLE_ENCODER_CRC);
    joints[1] = new RobotJoint(encoder, motor_driver, MOTOR2_POLE_PAIRS);
  }

  // axis 3
  {
    auto* encoder = new MT6835Encoder(spi0, PIN_ENCODER3_CS);
    auto* motor_driver = new TB6612MotorDriver(
      PIN_MOTOR_EN, PIN_M3_PWM_A_POS, PIN_M3_PWM_A_NEG, PIN_MOTOR_PWMAB,
      PIN_MOTOR_EN, PIN_M3_PWM_B_POS, PIN_M3_PWM_B_NEG, PIN_MOTOR_PWMAB
    );
	encoder->set_crc_enabled(ENABLE_ENCODER_CRC);
    joints[2] = new RobotJoint(encoder, motor_driver, MOTOR3_POLE_PAIRS);
  }

  // initialize axes
  for(int i=0; i<NUM_JOINTS; i++) {
    joints[i]->init(i);
    joints[i]->load_calibration();
  }

  // add tools
  robot_tools[0] = new PwmTool();
  ((PwmTool*)robot_tools[0])->init(PIN_TOOL1, 8000, 8);

  robot_tools[1] = new PwmTool();
  ((PwmTool*)robot_tools[1])->init(PIN_TOOL2, 8000, 8);

  // setup timer for updating the motion controller (which evaluates joint space path
  // segments and produces the current target position for the servo loops)
  float motion_controller_update_time_us = 500;
  add_repeating_timer_us(-motion_controller_update_time_us, 
                         Robot::update_motion_controller_isr, 
                         (void*)this, 
                         &motion_controller_update_timer);
}


void Robot::update_command_parser() {
  // process serial input
  if (Serial.available()) {
    char c = Serial.read();
    command_parser.add_input_character(c);
    // Serial.write(c);
  }

  // update command parse which will queue command to the path planner
  command_parser.update();

  // TESTING:
  //sleep_ms(10);
  //float pos_error = joints[1]->servo_controller->get_position_error();
  //LOG_INFO(">pos_error [µrad]: %f\n", pos_error*1e6);
  //Serial.printf(">pos_error [µrad]: %f\n", pos_error*1e6);#
  //LOG_INFO(">pos_x [mm]: %f", joints[1]->position);
  //update_servo_controllers(0.01f);
}

/**
 * Updates the path planner, that chops up kartesian path segments into joint space
 * path segments using the inverse kinematic model. It then enqueues these joint space path
 * segments for the motion controller.
 */
void Robot::update_path_planner() {
  // check if buffering starts
  uint64_t time = time_us_64();
  if(state == ERobotState::IDLE && path_planner.input_queue_size() > 0) {
    state = ERobotState::BUFFERING_PATH;
    path_buffering_start_time = time;
  }

  // check if execution starts
  uint64_t buffering_time = time-path_buffering_start_time;
  if(state == ERobotState::BUFFERING_PATH && buffering_time > path_buffering_time_us) {
    state = ERobotState::EXECUTING_PATH;
  }

  // execute path
  if(state == ERobotState::EXECUTING_PATH) {
    // update planner and generate joint space path segments
    path_planner.process(true);

    if(path_planner.all_finished())
      state = ERobotState::IDLE;
  }
}
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

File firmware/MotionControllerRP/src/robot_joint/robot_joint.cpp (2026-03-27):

// --------------------------------------------------------------------------------------
// Project: MicroManipulatorStepper
// License: MIT (see LICENSE file for full description)
//          All text in here must be included in any redistribution.
// Author:  M. S. (diffraction limited)
// --------------------------------------------------------------------------------------

#include <LittleFS.h> 
#include "robot_joint.h"
#include "hw_config.h"
#include "utilities/logging.h"
#include "utilities/utilities.h"
#include "servo_control/homing_controller.h"
#include "servo_control/actuator_calibration.h"

//*** FUNCTION **************************************************************************

//*** CLASS *****************************************************************************

//--- RobotJoint ------------------------------------------------------------------------

RobotJoint::RobotJoint(MT6835Encoder* encoder, 
                       TB6612MotorDriver* motor_driver,
                       int pole_pairs) 
{
  RobotJoint::encoder = encoder;
  RobotJoint::motor_driver = motor_driver;
  servo_controller = new ServoController(*motor_driver, *encoder, pole_pairs);
  position = 0.0f;
  velocity = 0.0f;
}

RobotJoint::~RobotJoint() {
  delete servo_controller;
  delete motor_driver;
  delete encoder;
  servo_controller = nullptr;
  motor_driver = nullptr;
  encoder = nullptr;
}

void RobotJoint::init(int joint_idx) {
  RobotJoint::joint_idx = joint_idx;

  if(encoder->init(0x5, 0x4) == false) {
    LOG_ERROR("Failed to initialize encoder for joint %i", joint_idx);
  }

  servo_controller->init(MOTOR_MAX_CURRENT_FACTOR);
  servo_controller->set_motor_enabled(false, false);
}

bool RobotJoint::calibrate(bool print_measurements) {
  LOG_INFO("Joint-%i: calibrating joint...", joint_idx);

  HomingController homing_controller;
  bool homing_ok = homing_controller.run_blocking(servo_controller, -HOMING_VELOCITY, 
                                                  360.0f*DEG_TO_RAD, HOMING_CURRENT,
                                                  ENCODER_ANGLE_TO_ROTOR_ANGLE,
                                                  CALIBRATION_RETRACTION_FIELD_ANGLE);
  if(homing_ok == false) {
    LOG_ERROR("Joint-%i: Calibration failed due to unsuccessful homing sequence", joint_idx);
    return false;
  }

  // measure lookup tables
  LookupTable encoder_raw_to_motor_pos_lut;
  LookupTable motor_pos_to_field_angle_lut;
  bool ok = measure_calibration_data(encoder_raw_to_motor_pos_lut, 
                                     motor_pos_to_field_angle_lut, 
                                     *servo_controller, 
                                     CALIBRATION_RANGE*DEG_TO_RAD,
                                     CALIBRATION_FIELD_VELOCITY, 
                                     256,
                                     print_measurements);
  if(!ok) {
    LOG_ERROR("Joint-%i: calibrating failed", joint_idx);
    return false;
  }

  servo_controller->set_enc_to_pos_lut(encoder_raw_to_motor_pos_lut);
  servo_controller->set_pos_to_field_lut(motor_pos_to_field_angle_lut);
  is_calibrated = true;
  is_homed = true;

  LOG_INFO("Joint-%i: calibrating joint successful.", joint_idx);

  return true;
}

void RobotJoint::update(float dt, float one_over_dt) {
  servo_controller->update(position, dt, one_over_dt);
}

void RobotJoint::update_target(float p, float v) {
  position = p;
  velocity = v;
}

bool RobotJoint::load_calibration() {
  std::string fn1 = calib_data_filename("enc_to_pos_lut").c_str();
  std::string fn2 = calib_data_filename("pos_to_field_lut").c_str();
  if(!LittleFS.exists(fn1.c_str()) || !LittleFS.exists(fn2.c_str())) {
    LOG_WARNING("Joint-%i: Not all calibration files found. Run joint calibration with M56.", joint_idx);
    return false;
  }

  LookupTable enc_to_pos_lut;
  LookupTable pos_to_field_lut;
  bool res = true; 
  res &= load_lut_from_file(enc_to_pos_lut, fn1.c_str());
  res &= load_lut_from_file(pos_to_field_lut, fn2.c_str());
  if(res == false)
    return false;

  servo_controller->set_enc_to_pos_lut(enc_to_pos_lut);
  servo_controller->set_pos_to_field_lut(pos_to_field_lut);

  is_calibrated = true;
  LOG_INFO("Joint-%i: Encoder lookup tables loaded (size=%i,%i)", 
           joint_idx, enc_to_pos_lut.size(), pos_to_field_lut.size());

  return true;
}

bool RobotJoint::store_calibration() {
  bool res = true;

  res &= save_lut_to_file(servo_controller->get_enc_to_pos_lut(), 
                          calib_data_filename("enc_to_pos_lut").c_str());
  res &= save_lut_to_file(servo_controller->get_pos_to_field_lut(), 
                          calib_data_filename("pos_to_field_lut").c_str());

  return res;
}

std::string RobotJoint::calib_data_filename(std::string data_name) const {
  return std::string("joint_")+std::to_string(joint_idx)+"_"+data_name+".dat";
}

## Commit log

2026-02-26 implement rotation homing
2026-03-08 add heating pin defs
2026-03-11 Updates and things
    [output_0.csv, output_1.csv, output_2.csv]
2026-03-12 move temperature to separate file
2026-03-16 Update with more v4 tests
    [output_1.csv]
2026-03-16 fix i2c issues
2026-03-18 Updates and stuff
    [output_0.csv, output_1.csv]
2026-03-20 Updates for working!!!
    [output_0.csv, raw_values.csv]
2026-03-23 Fix homing retraction angle
    [api.py, homing_controller.cpp]
2026-03-27 Move Image Validation to its own piece of software
    [data.xlsx]
2026-03-30 Update with better homing for z axis
2026-03-31 Update with intro info
    [data.xlsx, idx_to_coord.csv, movement_results.csv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]
2026-04-03 add PCB design files
    [heater_pcb.kicad_pcb, heater_pcb.kicad_sch, rot_platform_pcb.kicad_pcb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]
2026-04-08 Updates to stage usage
    [movement_test_no_grid.csv]
2026-04-08 Working Version
    [output_0.csv]
2026-04-29 clean up code and fixes on PCB (#4)
    * fix rotation negative sign issue, add warning message for encoder
    * update rotational stage PCB to V1.1
    Fixed a few issues in V1.0
    * add home and calibration debug command
    * cleaned up unused rotation code
    [rot_platform_pcb.kicad_pcb, rot_platform_pcb.kicad_sch]
2026-04-29 Updates with Step
    [Litho Base Mount.step]
2026-05-03 Add holder stl
    [Assembly_MicroManipulator-Assembly_MicroManipulator - Part 174.stl]
2026-05-03 Rename Assembly_MicroManipulator-Assembly_MicroManipulator - Part 174.stl to StandingBase.stl
    [StandingBase.stl]
